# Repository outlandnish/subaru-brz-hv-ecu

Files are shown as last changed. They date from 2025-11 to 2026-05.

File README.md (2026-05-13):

# Subaru BRZ HV ECU

> **SAFETY NOTICE:** This system controls high-voltage contactors on a traction battery pack.
> Incorrect firmware can result in arc flash, fire, or electrocution. Do not flash untested builds
> to hardware connected to a live HV pack.

This is the HV ECU for a Subaru BRZ EV conversion. It manages:
- **Battery management** — cell voltage monitoring, balancing, and protection via NXP MC33772 BCC ICs
- **HV contactor control** — precharge, engage, and safe shutdown via DRV8874 H-bridge drivers
- **CAN communication** — IVT-S current/voltage shunt (HV CAN), CHAdeMO EVSE controller (M3 CAN)
- **CANopen** — parameter access and spot-value reporting via libopeninv

## Hardware

See [`hardware/`](hardware/) for schematics and pin maps.

Key specs:
- MCU: STM32F413VH running FreeRTOS
- 16 Taycan modules (8 per BCC chain, two MC33772 chains)
- DRV8874 H-bridge drivers for HV and AC contactors
- IVT-S 1000 A current shunt on HV CAN bus
- CHAdeMO controller (Foccci) on M3 CAN bus

## Getting Started

Clone with submodules:

```bash
git clone --recurse-submodules <repo-url>
# or after a plain clone:
git submodule update --init --recursive
```

## Building and Flashing

This project uses [PlatformIO](https://platformio.org/).

```bash
# Build main firmware
pio run -e hv-ecu

# Flash via ST-Link
pio run -e hv-ecu --target upload

# Serial monitor (115200 baud)
pio device monitor
```

## First-Boot Procedure

1. Flash firmware with ST-Link connected and HV pack **disconnected**.
2. Open a serial monitor at 115200 baud.
3. Type `status` to verify BCC devices are detected and cell voltages are sensible.
4. Type `params` to review default charge parameters before connecting HV.
5. Connect HV pack. Type `hv connect` to initiate precharge sequence.

## Running Tests

Unit tests run on-target via PlatformIO Unity:

```bash
pio test -e bms-test
```

## License

MIT — see [LICENSE](LICENSE).

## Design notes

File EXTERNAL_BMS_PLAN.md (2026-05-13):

# BMS CAN Protocol v0.1
**Status:** Draft  
**Target Hardware:** Dual-chain MC33772B BMS with Taycan 6S2P modules  
**CAN Bus Speed:** 500 kbps  
**CRC Algorithm:** CRC-8/AUTOSAR (polynomial 0x2F, init 0xFF, reflect in/out none, final XOR 0xFF)

---

## Table of Contents

1. [Overview](#1-overview)
2. [Physical Layer](#2-physical-layer)
3. [Frame Map](#3-frame-map)
4. [Ecosystem Broadcast Frames (0x351–0x35C)](#4-ecosystem-broadcast-frames)
5. [Cell Voltage Frames (0x400–0x401)](#5-cell-voltage-frames-0x400-0x401)
6. [Balancing Status Frame (0x402)](#6-balancing-status-frame-0x402)
7. [Temperature Frame (0x403)](#7-temperature-frame-0x403)
8. [BMS Config Frame (0x404)](#8-bms-config-frame-0x404)
9. [Contactor Status Frame (0x405)](#9-contactor-status-frame-0x405)
10. [UDS Diagnostic Interface](#10-uds-diagnostic-interface)
    - [Sessions and Security](#101-sessions-and-security)
    - [Data Identifiers](#102-data-identifiers)
    - [Fault Codes (DTCs)](#103-fault-codes-dtcs)
    - [Routine Control](#104-routine-control)
    - [Firmware Update](#105-firmware-update)
11. [Timing](#11-timing)
12. [CRC Calculation](#12-crc-calculation)

---

## 1. Overview

This document defines the CAN communication protocol for a dual-chain BMS supporting Porsche Taycan battery modules. Each module contains one MC33772B IC managing 6 cells in a 6S2P configuration. The protocol operates at 500 kbps and is structured in three layers:

| Layer | Frames | Purpose |
|---|---|---|
| Ecosystem Broadcast | 0x351–0x35C | Pack-level data. Compatible with SimpBMS, Victron, SMA, Fronius, and most aftermarket EV conversion chargers and inverters |
| Custom Broadcast | 0x400–0x405 | Per-module cell voltages, balancing status, temperatures, BMS config, contactor state |
| UDS Diagnostic | 0x7E0 / 0x7E8 | Configuration, fault codes, balancing parameters, contactor config, firmware update |

### Hardware Assumptions

- **Chains:** 2 (Chain 0 and Chain 1)
- **Max modules per chain:** 15 (30 total)
- **Cells per module:** 6 (always — Taycan 6S2P)
- **Max total cells:** 180
- **Temperature sensors per module:** 2x external NTC (Temp_A, Temp_B) + 1x MC33772B internal die (Temp_Die)
- **Contactors:** Up to 4 (K1–K4)
- **Current/voltage sensing:** IVT-S

---

## 2. Physical Layer

| Parameter | Value |
|---|---|
| Bus speed | 500 kbps |
| Frame format | CAN 2.0B, 11-bit standard IDs |
| Termination | 120 Ω at each end of bus |
| BMS UDS request ID | 0x7E0 |
| BMS UDS response ID | 0x7E8 |
| CRC algorithm | CRC-8/AUTOSAR |

---

## 3. Frame Map

| CAN ID | Name | Type | Rate | Description |
|---|---|---|---|---|
| 0x351 | ChargeVoltageLimit | Broadcast | 1000 ms | Max charge voltage and current limits |
| 0x355 | StateOfCharge | Broadcast | 1000 ms | SOC and SOH |
| 0x356 | PackSummary | Broadcast | 500 ms | Pack voltage, current, temperature |
| 0x359 | FaultFlags | Broadcast | 500 ms | Aggregate protection fault flags |
| 0x35C | ChargerControl | Broadcast | 1000 ms | Charger enable/disable flags |
| 0x400 | CellVoltages_1_3 | Broadcast (MUX) | 100 ms/module | Cells 1–3 per module. MUX = module index (0–29) |
| 0x401 | CellVoltages_4_6 | Broadcast (MUX) | 100 ms/module | Cells 4–6 per module. MUX = module index (0–29) |
| 0x402 | BalancingStatus | Broadcast (MUX) | 500 ms/module | Per-module balancing bitmask, mode, and target. MUX = module index (0–29) |
| 0x403 | Temperature | Broadcast (MUX) | 500 ms/module | Per-module Temp_A, Temp_B, Temp_Die. MUX = module index (0–29) |
| 0x404 | BMSConfig | Broadcast | On change + 5 s | Chain topology, module counts, BMS state, protocol version |
| 0x405 | ContactorStatus | Broadcast | 100 ms | State of K1–K4 and pre-charge status |
| 0x406 | ExtPackSummary | Broadcast | 500 ms | High-resolution pack voltage (1 mV/LSB) and current (1 mA/LSB) for high-voltage packs |
| 0x7E0 | UDS Request | Request/Response | On demand | ISO 14229 diagnostic requests from external tool |
| 0x7E8 | UDS Response | Request/Response | On demand | ISO 14229 diagnostic responses from BMS |

---

## 4. Ecosystem Broadcast Frames

These frames follow the SimpBMS/BYD/Pylontech broadcast format. Compatible with:

- **Chargers:** Victron MultiPlus/Quattro, SMA Sunny Island, Fronius Symo/Gen24, KEBA P30
- **Inverters:** Victron VE.Can ecosystem, OpenInverter-based systems
- **Monitors:** SimpBMS, Batrium WatchMon (BYD/Pylontech mode)

The minimum required frames for charger compatibility are **0x351, 0x355, and 0x35C**.

### 0x351 — Charge Voltage & Current Limits

Transmitted every 1000 ms.

| Byte | Signal | Bits | Encoding | Description |
|---|---|---|---|---|
| 0–1 | ChargeVoltage | 16 | 10 mV/LSB, uint16 | Maximum charge voltage. Ecosystem standard (Victron/SMA/Fronius). Max encodable: 655.35 V — clamp to UINT16_MAX for packs above 655 V |
| 2–3 | ChargeCurrentLimit | 16 | 100 mA/LSB, uint16 | Maximum charge current |
| 4–5 | DischargeCurrentLimit | 16 | 100 mA/LSB, uint16 | Maximum discharge current |
| 6–7 | DischargeVoltage | 16 | 10 mV/LSB, uint16 | Minimum discharge voltage. Ecosystem standard. Same 655 V ceiling applies |

### 0x355 — State of Charge / Health

Transmitted every 1000 ms.

| Byte | Signal | Bits | Encoding | Description |
|---|---|---|---|---|
| 0–1 | SOC | 16 | 0.01%/LSB, uint16 | State of charge (0–10000 = 0.00–100.00%) |
| 2–3 | SOH | 16 | 0.01%/LSB, uint16 | State of health (0–10000 = 0.00–100.00%) |
| 4–5 | SOC_High | 16 | 0.01%/LSB, uint16 | High precision SOC (same scale, same value) |
| 6–7 | reserved | 16 | — | Set to 0x0000 |

> **Note:** SOH is user-configurable via UDS DID 0xD105. DCIR-based automatic SOH estimation is reserved for a future revision.

### 0x356 — Pack Summary

Transmitted every 500 ms.

| Byte | Signal | Bits | Encoding | Description |
|---|---|---|---|---|
| 0–1 | PackVoltage | 16 | 10 mV/LSB, int16 | Total pack voltage. Ecosystem standard. Overflows above 327 V — use 0x406 for high-voltage packs |
| 2–3 | PackCurrent | 16 | 100 mA/LSB, int16 | Pack current. Positive = charging, negative = discharging |
| 4–5 | PackTemp | 16 | 0.1°C/LSB, int16 | Highest temperature across all NTC sensors. 0x7FFF = invalid/not yet available |
| 6–7 | reserved | 16 | — | Set to 0x0000 |

### 0x359 — Fault Flags

Transmitted every 500 ms.

| Byte | Signal | Bits | Encoding | Description |
|---|---|---|---|---|
| 0 | ProtectionFlags_0 | 8 | Bitmask | Bit 0: OVP, Bit 1: UVP, Bit 2: OTP, Bit 3: UTP |
| 1 | ProtectionFlags_1 | 8 | Bitmask | Bit 0: OCP charge, Bit 1: OCP discharge |
| 2 | WarnFlags_0 | 8 | Bitmask | Bit 0: High V warn, Bit 1: Low V warn, Bit 2: High T warn |
| 3 | WarnFlags_1 | 8 | Bitmask | Bit 0: High charge current warn, Bit 1: High discharge current warn |
| 4 | ActiveModules | 8 | Count | Number of active modules |
| 5 | BalancingModules | 8 | Count | Number of modules currently balancing |
| 6–7 | reserved | 16 | — | Set to 0x0000 |

### 0x35C — Charger Control

Transmitted every 1000 ms.

| Byte | Signal | Bits | Encoding | Description |
|---|---|---|---|---|
| 0 | ChargerFlags | 8 | Bitmask | Bit 0: Charge enable, Bit 1: Force charge, Bit 2: Discharge enable |
| 1–7 | reserved | 56 | — | Set to 0x00 |

---

## 5. Cell Voltage Frames (0x400–0x401)

Cell voltages for each module are split across two independent CAN IDs, each carrying 3 of the 6 cells. Both frames use a standard MUX byte equal to the global module index (0–29) and are transmitted independently at 100 ms per module.

**Global module index convention:**
- Chain 0 modules: index 0–14
- Chain 1 modules: index 15–29

### 0x400 — Cell Voltages, Cells 1–3

Transmitted every 100 ms per module.

| Byte | Signal | Bits | Encoding | Description |
|---|---|---|---|---|
| 0 | MUX | 8 | Module index (0–29) | Global module index |
| 1–2 | Cell1_Voltage | 16 | 1 mV/LSB, uint16 | Cell 1 voltage |
| 3–4 | Cell2_Voltage | 16 | 1 mV/LSB, uint16 | Cell 2 voltage |
| 5–6 | Cell3_Voltage | 16 | 1 mV/LSB, uint16 | Cell 3 voltage |
| 7 | CRC8 | 8 | CRC-8/AUTOSAR | CRC over bytes 0–6 |

### 0x401 — Cell Voltages, Cells 4–6

Transmitted every 100 ms per module.

| Byte | Signal | Bits | Encoding | Description |
|---|---|---|---|---|
| 0 | MUX | 8 | Module index (0–29) | Global module index |
| 1–2 | Cell4_Voltage | 16 | 1 mV/LSB, uint16 | Cell 4 voltage |
| 3–4 | Cell5_Voltage | 16 | 1 mV/LSB, uint16 | Cell 5 voltage |
| 5–6 | Cell6_Voltage | 16 | 1 mV/LSB, uint16 | Cell 6 voltage |
| 7 | CRC8 | 8 | CRC-8/AUTOSAR | CRC over bytes 0–6 |

> **Note:** 0x400 and 0x401 are transmitted independently at the same rate. A receiver can expect both frames for each module index within the same 100 ms cycle. Frames for inactive modules (index >= Total_Modules from 0x404) are not transmitted.

---

## 6. Balancing Status Frame (0x402)

Broadcasts per-module balancing state. One frame per module per cycle, MUX = global module index.

### Frame Layout

Transmitted every 500 ms per module.

| Byte | Signal | Bits | Encoding | Description |
|---|---|---|---|---|
| 0 | MUX | 8 | Module index (0–29) | Global module index |
| 1 | Balance_Mask | 8 | Bitmask | Bits 0–5: cell N+1 currently balancing. Bits 6–7 reserved, set to 0 |
| 2 | Balance_Mode | 8 | Enum | 0x00 = Disabled, 0x01 = Delta-V, 0x02 = Absolute target |
| 3–4 | Balance_Param | 16 | 1 mV/LSB, uint16 | Mode 0x01: delta-V threshold in mV. Mode 0x02: absolute target voltage in mV |
| 5–6 | reserved | 16 | — | Set to 0x0000 |
| 7 | CRC8 | 8 | CRC-8/AUTOSAR | CRC over bytes 0–6 |

### Balance_Mode Encoding

| Value | Mode | Balance_Param Meaning |
|---|---|---|
| 0x00 | Disabled | Ignored — set to 0x0000 |
| 0x01 | Delta-V | Threshold in mV above minimum cell voltage. Balance any cell where V_cell > V_min + threshold |
| 0x02 | Absolute | Target voltage in mV. Balance any cell where V_cell > target |

> **Note:** Balance_Mode and Balance_Param are global settings repeated in every module frame so any single frame is self-contained. Balancing is controlled autonomously by the BMS. Use UDS Routine Control service 0xD001 to trigger a manual balance cycle.

---

## 7. Temperature Frame (0x403)

Broadcasts per-module temperature readings. One frame per module per cycle, MUX = global module index.

### Frame Layout

Transmitted every 500 ms per module.

| Byte | Signal | Bits | Encoding | Description |
|---|---|---|---|---|
| 0 | MUX | 8 | Module index (0–29) | Global module index |
| 1–2 | Temp_A | 16 | 0.01°C/LSB, int16 | NTC thermistor A. Range: −327.68°C to +327.67°C |
| 3–4 | Temp_B | 16 | 0.01°C/LSB, int16 | NTC thermistor B. Range: −327.68°C to +327.67°C |
| 5–6 | Temp_Die | 16 | 0.01°C/LSB, int16 | MC33772B internal die temperature |
| 7 | CRC8 | 8 | CRC-8/AUTOSAR | CRC over bytes 0–6 |

> **Note:** A value of 0x7FFF (32767) indicates an invalid or disconnected sensor. Die temperature has approximately 1°C internal resolution; sub-degree digits will be zero unless interpolation is applied.

---

## 8. BMS Config Frame (0x404)

Broadcasts BMS topology and state as a single fixed frame with no MUX. Transmitted on power-on, on any configuration change, and periodically every 5 seconds. Receivers should wait for this frame before parsing 0x400–0x403 to determine the active module count.

Configuration is **read-only via broadcast**. Write configuration via UDS only.

### Frame Layout

| Byte | Signal | Bits | Encoding | Description |
|---|---|---|---|---|
| 0 | Chain0_Modules | 8 | 0–15 | Number of active modules on chain 0 |
| 1 | Chain1_Modules | 8 | 0–15 | Number of active modules on chain 1 |
| 2 | Total_Modules | 8 | 0–30 | Total active modules across both chains |
| 3 | Protocol_Version | 8 | 0x01 | Protocol version. This document = 0x01 |
| 4 | BMS_State | 8 | Enum | See BMS_State encoding below |
| 5–6 | reserved | 16 | — | Set to 0x0000 |
| 7 | CRC8 | 8 | CRC-8/AUTOSAR | CRC over bytes 0–6 |

### BMS_State Encoding

| Value | State | Description |
|---|---|---|
| 0x00 | Init | BMS initialising, chain communication not yet established |
| 0x01 | Ready | BMS operational, HV system open |
| 0x02 | Active | HV system closed, normal operation |
| 0x03 | Balancing | Balancing in progress |
| 0x04 | Charging | Charge contactor closed, charging in progress |
| 0x05 | Fault | One or more active faults. See 0x359 and UDS DTCs for details |
| 0x06 | Precharge | Pre-charge sequence in progress |

---

## 9. Contactor Status Frame (0x405)

Broadcasts the state of all four contactors and the pre-charge sequence. Transmitted every 100 ms.

### Frame Layout

| Byte | Signal | Bits | Encoding | Description |
|---|---|---|---|---|
| 0 | Contactor_State | 8 | Bitmask | Bit 0: K1, Bit 1: K2, Bit 2: K3, Bit 3: K4. 1 = closed, 0 = open |
| 1 | Precharge_State | 8 | Enum | See Precharge_State encoding below |
| 2–3 | Precharge_Voltage | 16 | **100 mV/LSB, uint16** | IVT-S inverter-side voltage during pre-charge. Changed from 1 mV/LSB to avoid overflow above 65 V |
| 4–5 | Pack_Voltage | 16 | **100 mV/LSB, uint16** | IVT-S pack-side voltage. Changed from 1 mV/LSB to avoid overflow above 65 V |
| 6 | reserved | 8 | — | Set to 0x00 |
| 7 | CRC8 | 8 | CRC-8/AUTOSAR | CRC over bytes 0–6 |

### Precharge_State Encoding

| Value | State | Description |
|---|---|---|
| 0x00 | Idle | Pre-charge not active |
| 0x01 | In Progress | Pre-charge contactor closed, voltage rising |
| 0x02 | Complete | Delta-V threshold met, ready to close main positive |
| 0x03 | Timeout | Pre-charge did not complete within configured timeout |
| 0x04 | Fault | Pre-charge fault (welded contactor, voltage sensor fault, etc.) |

### Default Contactor Assignment

| Contactor | Default Role | Configurable via UDS |
|---|---|---|
| K1 | Main negative | Yes |
| K2 | Main positive | Yes |
| K3 | Pre-charge | Yes |
| K4 | Charge path | Yes |

> **Note:** Contactor roles and pre-charge completion threshold are configurable via UDS DIDs 0xD200–0xD206. Pre-charge completion is determined by IVT-S voltage delta (V_pack − V_inverter < threshold), not by a fixed timer.

---

## 10. Extended Pack Summary Frame (0x406)

High-resolution pack voltage and current for receivers that need sub-100 mV precision or support packs above 327 V. Not part of the ecosystem broadcast format — not parsed by Victron/SMA/Fronius chargers. Transmitted at the same rate as 0x356.

### Frame Layout

Transmitted every 500 ms.

| Byte | Signal | Bits | Encoding | Description |
|---|---|---|---|---|
| 0–3 | PackVoltage | 32 | 1 mV/LSB, uint32 | Total pack voltage, little-endian. Range 0–4294967 V |
| 4–7 | PackCurrent | 32 | 1 mA/LSB, int32 | Pack current, little-endian. Positive = charging, negative = discharging |

> **Note:** No CRC — frame is 8 bytes, all payload. Temperature is omitted until BCC NTC readback is wired in; use 0x403 for per-module temperatures in the meantime.

---

## 11. UDS Diagnostic Interface

The UDS interface provides configuration, fault management, and firmware update over ISO 14229. Accessible with any UDS-capable tool (Vector CANalyzer, PEAK PCAN, python-udsoncan, etc.).

| Parameter | Value |
|---|---|
| Request ID | 0x7E0 |
| Response ID | 0x7E8 |
| Transport layer | ISO 15765-2 CAN TP |
| Addressing | Physical (1:1) |

---

### 10.1 Sessions and Security

#### Diagnostic Sessions (Service 0x10)

| Session | ID | Capabilities | Timeout |
|---|---|---|---|
| Default | 0x01 | Read all DIDs, read DTCs | No timeout |
| Extended Diagnostic | 0x03 | Read + write all DIDs, clear DTCs, routine control | 5 s inactivity |
| Programming | 0x02 | Firmware update only | Must unlock Security Level 2 first |

#### Security Access (Service 0x27)

| Level | RequestSeed | SendKey | Required For |
|---|---|---|---|
| Level 1 | 0x01 | 0x02 | Write DIDs in extended session |
| Level 2 | 0x11 | 0x12 | Programming session (firmware update) |

> **Note:** Seed/key algorithm TBD. Minimum recommendation: HMAC-SHA256 with a device-unique seed. Three consecutive failed attempts must lock security access for 10 minutes.

---

### 10.2 Data Identifiers

#### Read-Only DIDs (Service 0x22 — Default Session)

| DID | Name | Size | Encoding | Description |
|---|---|---|---|---|
| 0xF190 | DeviceSerial | 17 B | ASCII | Device serial number |
| 0xF187 | PartNumber | 10 B | ASCII | BMS hardware part number |
| 0xF189 | SoftwareVersion | 4 B | uint8 × 4 | Major.Minor.Patch.Build |
| 0xF195 | HardwareVersion | 2 B | uint8 × 2 | Major.Minor |
| 0xD000 | BMS_State | 1 B | Enum | See BMS_State encoding in §8 |
| 0xD001 | Pack_Voltage | 4 B | int32, 1 mV/LSB | Total pack voltage from IVT-S |
| 0xD002 | Pack_Current | 4 B | int32, 1 mA/LSB | Pack current. Positive = charging |
| 0xD003 | Cell_Voltage_Min | 2 B | uint16, 1 mV/LSB | Minimum cell voltage across all cells |
| 0xD004 | Cell_Voltage_Max | 2 B | uint16, 1 mV/LSB | Maximum cell voltage across all cells |
| 0xD005 | Cell_Voltage_Delta | 2 B | uint16, 1 mV/LSB | Max − Min cell voltage |
| 0xD006 | Cell_Voltage_Avg | 2 B | uint16, 1 mV/LSB | Average cell voltage across all cells |
| 0xD007 | Temp_Max | 2 B | int16, 0.01°C/LSB | Highest NTC temperature across all modules |
| 0xD008 | Temp_Min | 2 B | int16, 0.01°C/LSB | Lowest NTC temperature across all modules |
| 0xD009 | SOC | 2 B | uint16, 0.01%/LSB | State of charge |
| 0xD00A | SOH | 2 B | uint16, 0.01%/LSB | State of health (user-configured) |
| 0xD00B | Cell_Voltages_All | 2 B × N×6 | uint16, 1 mV/LSB | All cell voltages sequentially. N = Total_Modules, 6 cells per module |
| 0xD00C | Temps_All | 2 B × N×3 | int16, 0.01°C/LSB | All temperatures sequentially: Temp_A, Temp_B, Temp_Die per module |
| 0xD00D | Balance_Status_All | 1 B × N | Bitmask | Per-module balance mask. N = Total_Modules |
| 0xD00E | Chain0_Modules | 1 B | uint8 | Active module count on chain 0 |
| 0xD00F | Chain1_Modules | 1 B | uint8 | Active module count on chain 1 |
| 0xD010 | Total_Modules | 1 B | uint8 | Total modules across both chains |
| 0xD011 | Contactor_State | 1 B | Bitmask | Current state of K1–K4. See §9 |
| 0xD012 | Precharge_State | 1 B | Enum | Current pre-charge state. See §9 |
| 0xD013 | IVT_Pack_Voltage | 4 B | int32, 1 mV/LSB | IVT-S pack-side voltage |
| 0xD014 | IVT_Inverter_Voltage | 4 B | int32, 1 mV/LSB | IVT-S inverter-side voltage |

#### Read/Write DIDs (Service 0x2E — Extended Session + Security Level 1)

**Balancing Configuration**

| DID | Name | Size | Encoding | Description |
|---|---|---|---|---|
| 0xD100 | Balance_Mode | 1 B | Enum | 0x00 = Disabled, 0x01 = Delta-V, 0x02 = Absolute |
| 0xD101 | Balance_DeltaV_Threshold | 2 B | uint16, 1 mV/LSB | Delta-V threshold in mV. Active when Balance_Mode = 0x01 |
| 0xD102 | Balance_Absolute_Target | 2 B | uint16, 1 mV/LSB | Absolute target voltage in mV. Active when Balance_Mode = 0x02 |
| 0xD103 | Balance_Inhibit_Pack_Voltage | 2 B | uint16, 10 mV/LSB | Minimum pack voltage below which balancing is inhibited |
| 0xD104 | Balance_Min_Cell_Voltage | 2 B | uint16, 1 mV/LSB | Minimum cell voltage below which that cell will not be balanced |

**SOC / SOH Configuration**

| DID | Name | Size | Encoding | Description |
|---|---|---|---|---|
| 0xD105 | SOH_Override | 2 B | uint16, 0.01%/LSB | User-configured SOH value written to 0x355 directly |
| 0xD106 | SOC_Method | 1 B | Enum | 0x00 = Coulomb counting, 0x01 = OCV lookup (reserved for future) |

**Protection Thresholds**

| DID | Name | Size | Encoding | Description |
|---|---|---|---|---|
| 0xD110 | OVP_Threshold | 2 B | uint16, 1 mV/LSB | Cell overvoltage protection trip threshold |
| 0xD111 | OVP_Warning | 2 B | uint16, 1 mV/LSB | Cell overvoltage warning threshold |
| 0xD112 | UVP_Threshold | 2 B | uint16, 1 mV/LSB | Cell undervoltage protection trip threshold |
| 0xD113 | UVP_Warning | 2 B | uint16, 1 mV/LSB | Cell undervoltage warning threshold |
| 0xD114 | OTP_Threshold | 2 B | int16, 0.01°C/LSB | Overtemperature protection trip threshold |
| 0xD115 | OTP_Warning | 2 B | int16, 0.01°C/LSB | Overtemperature warning threshold |
| 0xD116 | UTP_Threshold | 2 B | int16, 0.01°C/LSB | Undertemperature protection trip threshold |
| 0xD117 | UTP_Warning | 2 B | int16, 0.01°C/LSB | Undertemperature warning threshold |
| 0xD118 | OCP_Charge_Threshold | 4 B | uint32, 1 mA/LSB | Overcurrent protection threshold for charge |
| 0xD119 | OCP_Discharge_Threshold | 4 B | uint32, 1 mA/LSB | Overcurrent protection threshold for discharge |

**Contactor Configuration**

| DID | Name | Size | Encoding | Description |
|---|---|---|---|---|
| 0xD200 | K1_Role | 1 B | Enum | 0x00 = Main negative, 0x01 = Main positive, 0x02 = Pre-charge, 0x03 = Charge path, 0xFF = Disabled |
| 0xD201 | K2_Role | 1 B | Enum | Same encoding as K1_Role |
| 0xD202 | K3_Role | 1 B | Enum | Same encoding as K1_Role |
| 0xD203 | K4_Role | 1 B | Enum | Same encoding as K1_Role |
| 0xD204 | Precharge_Completion_Threshold | 2 B | uint16, 1 mV/LSB | Delta-V between pack and inverter side below which pre-charge is considered complete |
| 0xD205 | Precharge_Timeout | 2 B | uint16, 1 ms/LSB | Maximum pre-charge duration before fault |
| 0xD206 | Precharge_Min_Voltage | 2 B | uint16, 1 mV/LSB | Minimum inverter-side voltage to consider pre-charge complete |

**Chain Configuration**

| DID | Name | Size | Encoding | Description |
|---|---|---|---|---|
| 0xD300 | Chain0_Module_Count | 1 B | uint8, 0–15 | Number of modules on chain 0 |
| 0xD301 | Chain1_Module_Count | 1 B | uint8, 0–15 | Number of modules on chain 1 |

> **Note:** Writing chain module counts triggers a BMS re-initialisation sequence. The BMS transitions to Init state, re-enumerates the chain, then returns to Ready state. A 0x404 config broadcast is sent immediately after re-initialisation completes.

---

### 10.3 Fault Codes (DTCs)

Fault codes are read using UDS Service 0x19 (ReadDTCInformation) and cleared using Service 0x14 (ClearDiagnosticInformation). Clearing DTCs requires Extended Session + Security Level 1.

| DTC | Name | Description |
|---|---|---|
| 0xC00001 | Cell_Overvoltage | One or more cells exceeded OVP_Threshold |
| 0xC00002 | Cell_Undervoltage | One or more cells fell below UVP_Threshold |
| 0xC00003 | Overtemperature | One or more sensors exceeded OTP_Threshold |
| 0xC00004 | Undertemperature | One or more sensors fell below UTP_Threshold |
| 0xC00005 | OCP_Charge | Charge current exceeded OCP_Charge_Threshold |
| 0xC00006 | OCP_Discharge | Discharge current exceeded OCP_Discharge_Threshold |
| 0xC00007 | Precharge_Timeout | Pre-charge did not complete within Precharge_Timeout |
| 0xC00008 | Precharge_Fault | Pre-charge fault (welded contactor suspected or voltage sensor fault) |
| 0xC00009 | Contactor_Fault | Contactor feedback mismatch (commanded state ≠ measured state) |
| 0xC0000A | Chain0_Comm_Fault | SPI communication fault on chain 0 |
| 0xC0000B | Chain1_Comm_Fault | SPI communication fault on chain 1 |
| 0xC0000C | IVT_Comm_Fault | IVT-S communication fault |
| 0xC0000D | Cell_Voltage_Sensor_Fault | MC33772B reported internal voltage measurement fault |
| 0xC0000E | Temp_Sensor_Fault | One or more temperature sensors reading 0x7FFF (disconnected or out of range) |
| 0xC0000F | Config_Invalid | Stored configuration checksum failure — BMS running with defaults |

---

### 10.4 Routine Control

Routines are invoked using UDS Service 0x31 (RoutineControl). All routines require Extended Session + Security Level 1.

| Routine ID | Name | Description |
|---|---|---|
| 0xD001 | Manual_Balance_Cycle | Triggers a single balancing pass using current Balance_Mode and Balance_Param. Returns when complete or on fault |
| 0xD002 | Balance_Stop | Immediately halts any active balancing on all modules |
| 0xD003 | Contactor_Open_All | Opens all contactors. For service/safety use only |
| 0xD004 | Precharge_Sequence | Manually triggers the pre-charge and close sequence |
| 0xD005 | Chain_Reinit | Re-initialises SPI chain enumeration without full BMS restart |
| 0xD006 | Clear_All_DTCs | Clears all stored DTCs. Equivalent to Service 0x14 with group 0xFFFFFF |
| 0xD007 | Save_Config | Persists all current DID values to non-volatile storage |

---

### 10.5 Firmware Update

Firmware update uses the standard UDS programming sequence. Programming session requires Security Level 2.

**Sequence:**

```
1. 0x10 0x02                         — Enter programming session
2. 0x27 0x11 → 0x27 0x12 <key>      — Unlock Security Level 2
3. 0x34 ...                          — Request download (address, length, compression)
4. 0x36 ... (repeat)                 — Transfer data blocks
5. 0x37                              — Request transfer exit
6. 0x31 0xFF 0x01                    — Validate firmware checksum (routine 0xFF01)
7. 0x11 0x01                         — ECU reset
```

> **Note:** The BMS will not close contactors while in programming session. If contactors are already closed when a programming session is requested, the request will be rejected with NRC 0x22 (conditionsNotCorrect).

---

## 11. Timing

| Frame | Interval | Notes |
|---|---|---|
| 0x351 | 1000 ms | |
| 0x355 | 1000 ms | |
| 0x356 | 500 ms | |
| 0x359 | 500 ms | |
| 0x35C | 1000 ms | |
| 0x400 | 100 ms/module | Full cycle = Total_Modules × 100 ms |
| 0x401 | 100 ms/module | Full cycle = Total_Modules × 100 ms. Transmitted independently of 0x400 |
| 0x402 | 500 ms/module | Full cycle = Total_Modules × 500 ms |
| 0x403 | 500 ms/module | Full cycle = Total_Modules × 500 ms |
| 0x404 | 5000 ms + on change | Always transmitted on power-on before other custom frames |
| 0x405 | 100 ms | |

> **Note:** At maximum configuration (30 modules), 0x400 and 0x401 each complete a full cycle in 3000 ms (30 frames × 100 ms). Bus load at maximum configuration at 500 kbps is well under 10%.

---

## 12. CRC Calculation

All custom broadcast frames (0x400–0x405) include a CRC-8/AUTOSAR checksum in byte 7, calculated over bytes 0–6.

**Algorithm parameters:**

| Parameter | Value |
|---|---|
| Polynomial | 0x2F |
| Initial value | 0xFF |
| Input reflection | No |
| Output reflection | No |
| Final XOR | 0xFF |
| Check value | 0xDF (CRC of ASCII "123456789") |

**Reference C implementation:**

```c
static const uint8_t crc8_autosar_table[256] = {
    0x00, 0x2F, 0x5E, 0x71, 0xBC, 0x93, 0xE2, 0xCD,
    /* ... full 256-entry table ... */
};

uint8_t crc8_autosar(const uint8_t *data, size_t len) {
    uint8_t crc = 0xFF;
    for (size_t i = 0; i < len; i++) {
        crc = crc8_autosar_table[crc ^ data[i]];
    }
    return crc ^ 0xFF;
}

/* Usage: byte 7 = crc8_autosar(frame, 7) */
```

> **Note:** The MC33772B uses CRC-8/AUTOSAR internally on its SPI bus. The same lookup table used for SPI communication can be reused directly for CAN frame CRCs.

---

*BMS CAN Protocol v0.1 — Draft. All frame definitions, DID addresses, and DTC codes are subject to change prior to v1.0 release.*

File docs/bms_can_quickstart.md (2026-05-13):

# BMS CAN Broadcaster — Integrator Quickstart

**DBC file:** [`bms_can_protocol.dbc`](../bms_can_protocol.dbc)

---

## 1. Hardware Setup

| Signal | Pin | Notes |
|---|---|---|
| HV CAN RX | `HV_CAN_RX` | 500 kbps, 120 Ω termination required at each end |
| HV CAN TX | `HV_CAN_TX` | |
| IVT-S shunt | HV CAN bus | Responds to frames 0x521–0x528 and 0x511 |
| BCC chain 0 | SPI (`BCC0_TX_CS`, `BCC0_INTB`, `BCC0_ENABLE`) | MC33772B, up to 15 modules |
| BCC chain 1 | SPI (`BCC1_TX_CS`, `BCC1_INTB`, `BCC1_ENABLE`) | MC33772B, up to 15 modules |
| Debug serial | 115200 baud | Available in `DEBUG` builds |

All CAN broadcast frames (0x351–0x405) are transmitted on **HV CAN at 500 kbps**.

---

## 2. Startup Sequence

On power-on the BMS transmits **0x404 (BMSConfig)** immediately before any other custom frames. Receivers should wait for this frame to determine the active module count before parsing 0x400–0x403.

The 0x404 frame then repeats every **5 seconds**.

---

## 3. Frame Summary

| CAN ID | Name | Rate | Purpose |
|---|---|---|---|
| 0x351 | ChargeVoltageLimit | 1000 ms | Pack charge/discharge voltage and current limits — ecosystem format |
| 0x355 | StateOfCharge | 1000 ms | SOC and SOH |
| 0x356 | PackSummary | 500 ms | Pack voltage, current, temperature |
| 0x359 | FaultFlags | 500 ms | Protection and warning flags, active module count |
| 0x35C | ChargerControl | 1000 ms | Charge enable / discharge enable |
| 0x400 | CellVoltages_1_3 | 100 ms/module | Cells 1–3, MUX = module index |
| 0x401 | CellVoltages_4_6 | 100 ms/module | Cells 4–6, MUX = module index |
| 0x402 | BalancingStatus | 500 ms/module | Per-module balance mask, mode, target |
| 0x403 | Temperature | 500 ms/module | Temp_A, Temp_B, Temp_Die per module |
| 0x404 | BMSConfig | 5000 ms + on change | Chain topology, module count, BMS state |
| 0x405 | ContactorStatus | 100 ms | K1–K4 state, pre-charge state and voltages |
| 0x406 | ExtPackSummary | 500 ms | High-resolution pack voltage (1 mV/LSB) and current (1 mA/LSB) — non-ecosystem |

Frames 0x351, 0x355, and 0x35C are the **minimum required** for charger compatibility with Victron, SMA, and Fronius systems.

### Module indexing

Modules are addressed globally across both chains:

- **Chain 0:** module index 0–14
- **Chain 1:** module index 15–29

The active count for each chain is broadcast in 0x404 (`Chain0_Modules`, `Chain1_Modules`). Only indices below the active count produce frames.

---

## 4. Signal Encodings

Key encoding decisions that differ from common BMS implementations:

| Frame | Signal | Encoding | Why |
|---|---|---|---|
| 0x356 | PackVoltage | int16, **10 mV/LSB** | Ecosystem standard — overflows above 327 V, use 0x406 for high-voltage packs |
| 0x406 | PackVoltage | uint32, **1 mV/LSB** | Extended frame — 1 mV resolution, supports up to ~4294 V |
| 0x406 | PackCurrent | int32, **1 mA/LSB** | Extended frame — 1 mA resolution |
| 0x405 | Precharge_Voltage | uint16, **100 mV/LSB** | uint16 at 1 mV/LSB overflows at 65 V |
| 0x405 | Pack_Voltage | uint16, **100 mV/LSB** | Same reason |
| 0x351 | ChargeVoltage | uint16, **10 mV/LSB** | Ecosystem standard — Victron/SMA/Fronius require this encoding |
| 0x351 | DischargeVoltage | uint16, **10 mV/LSB** | Ecosystem standard. Max encodable: 655.35 V |
| 0x356 | PackTemp | int16, 0.1°C/LSB | **0x7FFF = invalid** — BCC NTC readback not yet wired in firmware |
| 0x403 | Temp_A/B/Die | int16, 0.01°C/LSB | **0x7FFF = invalid** — same reason |

---

## 5. CRC

Frames 0x400–0x405 include a **CRC-8/AUTOSAR** checksum in byte 7, calculated over bytes 0–6.

| Parameter | Value |
|---|---|
| Polynomial | 0x2F |
| Initial value | 0xFF |
| Input/output reflection | None |
| Final XOR | 0xFF |
| Check value | 0xDF (CRC of "123456789") |

Frames 0x351–0x35C do **not** include a CRC (ecosystem format).

---

## 6. Configuration

### 6.1 Compile-time parameters (set before flashing)

Parameters are stored in non-volatile memory and loaded at boot. They can be updated by writing to parameter storage before flashing. There is currently **no runtime configuration interface** — UDS (§10 of the protocol spec) is planned but not yet implemented.

#### BCC Hardware

| Parameter | Unit | Range | Default | Description |
|---|---|---|---|---|
| `bcc0DeviceCount` | — | 0–15 | 8 | Number of MC33772B devices on chain 0 |
| `bcc0DeviceType` | 0=MC33771, 1=MC33772 | 0–1 | 1 | IC type for chain 0 |
| `bcc1DeviceCount` | — | 0–15 | 8 | Number of MC33772B devices on chain 1 |
| `bcc1DeviceType` | 0=MC33771, 1=MC33772 | 0–1 | 1 | IC type for chain 1 |

#### Battery

| Parameter | Unit | Range | Default | Description |
|---|---|---|---|---|
| `targetCellVolt` | mV | 3000–4300 | 3600 | Per-cell charge target voltage |
| `batteryCapacity` | Ah | 10–200 | 50 | Total pack capacity (used for SOC coulomb counting) |
| `minSocPercent` | % | 0–50 | 10 | SOC floor — BMS will not discharge below this |
| `maxSocPercent` | % | 50–100 | 100 | SOC ceiling |
| `initSocPercent` | % | 0–100 | 50 | Initial SOC estimate on first boot before coulomb counting converges |

#### Charging

| Parameter | Unit | Range | Default | Description |
|---|---|---|---|---|
| `maxChargeCurrent` | A | 5–200 | 30 | Maximum charge current limit (broadcast in 0x351 `ChargeCurrentLimit`) |
| `balanceThreshold` | mV | 10–200 | 50 | Cell delta-V above which balancing activates (also broadcast in 0x402 `Balance_Param`) |
| `balanceTarget` | mV | 5–100 | 10 | Cell delta-V below which balancing deactivates and charging resumes |
| `balanceTimerMin` | min | 1–60 | 5 | Maximum duration of a single balancing pass |
| `measureInterval` | ms | 10–1000 | 20 | Voltage measurement interval |

#### HV System

| Parameter | Unit | Range | Default | Description |
|---|---|---|---|---|
| `prechargeMargin` | V | 1–50 | 10 | Acceptable V_pack − V_inverter delta for precharge completion |
| `prechargeTimeout` | ms | 1000–30000 | 5000 | Maximum precharge duration before fault |
| `prechargeCheckInt` | ms | 10–1000 | 100 | How often precharge voltage is checked |

#### Contactor PWM (economizer mode)

| Parameter | Unit | Range | Default | Description |
|---|---|---|---|---|
| `pwmFrequency` | Hz | 1000–50000 | 25000 | Contactor PWM frequency |
| `engageDuty` | % | 50–100 | 100 | Duty cycle during initial engagement |
| `holdDuty` | % | 10–80 | 30 | Hold duty cycle after engagement |
| `engageTime` | ms | 10–500 | 100 | Duration of full-duty engage phase before switching to hold |

#### Timing

| Parameter | Unit | Range | Default | Description |
|---|---|---|---|---|
| `commTimeout` | ms | 1000–30000 | 5000 | BCC communication loss timeout before fault |
| `faultCheckInt` | ms | 100–30000 | 5000 | How often fault registers are read from BCC |

### 6.2 UDS configuration (planned — not yet implemented)

The protocol spec defines a full UDS interface (0x7E0 / 0x7E8) for runtime configuration of balancing parameters, protection thresholds, contactor roles, SOH, and chain topology. This is not implemented in the current firmware. All configuration is currently done at flash time.

See `EXTERNAL_BMS_PLAN.md §11` for the planned DID map.

---

## 7. Read-only diagnostic values

These values are maintained internally by the BMS and readable via the parameter interface (not broadcast over CAN).

| Value | Unit | Description |
|---|---|---|
| `packVoltage` | V | IVT-S V1 pack-side voltage |
| `packCurrent` | A | IVT-S current |
| `soc` | % | State of charge (integer) |
| `socPrecise` | % | State of charge (float) |
| `cellVoltMin` | mV | Minimum cell voltage across all cells |
| `cellVoltMax` | mV | Maximum cell voltage across all cells |
| `cellVoltDiff` | mV | Max − Min cell voltage |
| `safeChargeCurrent` | A | Computed safe charge current |
| `bmsState` | — | Internal BMS state enum |
| `hvState` | — | HV state machine state |
| `bcc0Initialized` | — | BCC chain 0 init status |
| `bcc1Initialized` | — | BCC chain 1 init status |
| `faultStatus` | — | Raw BCC fault register bitmask |
| `lasterr` | — | Last fault code |
| `ivtCurrent` | A | IVT-S current (raw CAN value) |
| `ivtVoltage1` | V | IVT-S V1 (pack side) |
| `ivtVoltage2` | V | IVT-S V2 (inverter side) |
| `ivtTemperature` | C | IVT-S temperature |
| `ivtPower` | kW | IVT-S computed power |

---

## 8. Fault flags (0x359)

| Bit | Signal | Source |
|---|---|---|
| Byte 0, bit 0 | OVP | BCC `CELL_OV` fault register |
| Byte 0, bit 1 | UVP | BCC `CELL_UV` fault register |
| Byte 0, bit 2 | OTP | BCC `AN_OT_UT` register, over-temp bits |
| Byte 0, bit 3 | UTP | BCC `AN_OT_UT` register, under-temp bits |
| Byte 1, bit 0 | OCP_Charge | IVT current > 0 while `has_faults()` |
| Byte 1, bit 1 | OCP_Discharge | IVT current < 0 while `has_faults()` |
| Byte 2, bits 0–2 | WarnHighV, WarnLowV, WarnHighT | Same sources as protection flags |
| Byte 4 | ActiveModules | 0 if BCC comm fault, else total module count |
| Byte 5 | BalancingModules | Total modules when in `BMS_CellBalancing` state, else 0 |

---

## 9. BMS state machine

States broadcast in 0x404 `BMS_State` and 0x405 `Precharge_State`:

```
              ┌─────────┐
   boot       │  Init   │
─────────────►│  0x00   │
              └────┬────┘
                   │ BCC chains enumerated
              ┌────▼────┐
              │  Ready  │◄──── HV_Shutdown
              │  0x01   │
              └────┬────┘
                   │ start_charging() / start_drive_mode()
          ┌────────▼────────┐
          │   Precharge     │
          │     0x06        │
          └────────┬────────┘
                   │ V_inverter ≈ V_pack (within prechargeMargin)
          ┌────────▼────────┐
          │ Charging/Active │
          │   0x04 / 0x02   │
          └────────┬────────┘
                   │ cell delta-V > balanceThreshold
          ┌────────▼────────┐
          │   Balancing     │
          │     0x03        │
          └─────────────────┘
                   
  Any state ──fault──► Fault (0x05)
```

---

## 10. Charger integration (ecosystem frames)

For Victron/SMA/Fronius chargers, the minimum subscription is:

1. **0x351** — pack charge voltage and current limits (sent every 1 s)
2. **0x355** — SOC and SOH (sent every 1 s)
3. **0x35C** — charge enable flag (sent every 1 s)

The charger must see all three frames within its timeout window (typically 3–5 s) to remain enabled. The `ChargeEnable` bit in 0x35C goes high when `BMS_State` is `Charging` or `Idle` and no faults are active. `DischargeEnable` goes high when `HV_State` is `Active` and no faults are active.

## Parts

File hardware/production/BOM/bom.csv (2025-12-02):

Designator | Footprint | Quantity | Value | LCSC Part #
C1, C9 | 0402 | 2 | 1 nF
C10, C12, C2, C4 | 0402 | 4 | 100 nF
C11, C21, C3, C44 | 0805 | 4 | 2.2 uF
C13, C28, C29, C5 | 0402 | 4 | 4.7 nF
C14, C15, C6, C7 | 0402 | 4 | 68 pF
C16, C8 | 0402 | 2 | 100 pF
C17, C18 | 0402 | 2 | 6 pF
C19, C20 | 0402 | 2 | 18 pF
C22, C23, C24, C25, C30, C31, C32, C43 | 0402 | 8 | 0.1 uF
C26 | 0402 | 1 | 1.0 uF
C27 | 0805 | 1 | 4.7 uF
C34, C35, C36, C50, C52, C56, C58 | 0805 | 7 | 100nF | C49678
C37 | 0805 | 1 | 47pF | C14857
C38 | 0805 | 1 | 22pF | C1804
C39, C40, C42, C53, C54, C55, C59, C60, C61 | 1210 | 9 | 22uF | C12891
C41 | 0805 | 1 | 10 uF | C14857
C51, C57 | 0805 | 2 | 22nF | C1729
D1, D2, D3, D4 | SOD2512X110N | 4 | PESD5V0V1BA,115
D10, D11, D13, D14, D15, D16, D17, D5, D8, D9 | XL-1010RGBC-WS2812B | 10 | ~
D12 | 0603 | 1 | LED
D23, D24 | D_SMA | 2 | SS15
D6, D7 | SOT-23_ONS | 2 | SZNUP2105LT1G
IC1, IC2 | SOIC127P600X175-16N | 2 | MC33664ATL1EG
IC4, IC5 | SOP65P640X120-17N | 2 | DRV8874QPWPRQ1 | C1855818
J3 | ST-Link MINIV3 BTB | 1 | Conn_01x10_Pin
J4 | DTM1312PA12PBR008 | 1 | DTM1312PA12PBR008
L1 | L_6.3x6.3_H3 | 1 | 10uH | C408412
R1, R10, R11, R12, R13, R14, R2, R3, R4, R5, R6, R9 | 0402 | 12 | 10K
R15, R16, R7, R8 | 0603 | 4 | 75 R
R17 | 0603 | 1 | 10k
R18 | 0402 | 1 | 15k
R19 | 0402 | 1 | 3.3k
R24, R25, R26, R27 | 0603 | 4 | 60R .25W
R30, R36 | 0805 | 2 | 560 | C28636
R31, R37 | 0805 | 2 | 2k7 | C17530
R32 | 0603 | 1 | 680R
R33 | 0805 | 1 | 22k | C17560
R51 | 0805 | 1 | 100k | C149504
R52 | 0805 | 1 | 33k | C17633
T1, T2 | SOP254P940X572-6N | 2 | HM2103NLT
U1, U4 | SMA_UNI_STM | 2 | SMAJ16A-TR | C908770
U2, U3 | SOIC-8_3.9x4.9mm_P1.27mm | 2 | SN65HVD230
U5 | SOT-223-3_TabPin2 | 1 | AMS1117-3.3 | C6186
U7 | SOT-23-6 | 1 | TPS54302 | C311983
U9 | LQFP-100_14x14mm_P0.5mm | 1 | STM32F413VHTx
Y1 | Crystal_SMD_3215-2Pin_3.2x1.5mm | 1 | 32.768 kHz
Y2 | Crystal_SMD_HC49-SD | 1 | 8MHz

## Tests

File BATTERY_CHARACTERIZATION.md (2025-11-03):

# Battery Characterization Tool

This tool reads GUID, configuration registers, and fuse mirror data from up to 8 batteries on each BCC chain (BCC0 and BCC1) and outputs the data in CSV format.

## Overview

The battery characterization application is a separate PlatformIO environment that:
- Initializes both BCC0 and BCC1 chains
- Detects up to 8 MC33772C devices on each chain (16 batteries total)
- Reads GUID from each battery
- Reads all configuration registers (44 registers for MC33772C)
- Reads all fuse mirror data (32 fuse addresses for MC33772C)
- Outputs all data in CSV format via serial port

## Hardware Setup

1. Connect up to 8 batteries to BCC0 daisy chain
2. Connect up to 8 batteries to BCC1 daisy chain
3. Ensure proper power supply to the board
4. Connect ST-Link debugger or USB cable

## Building and Uploading

### Build the application
```bash
pio run -e battery-char
```

### Upload to board
```bash
pio run -e battery-char -t upload
```

## Capturing Data

### Method 1: Using Python Capture Script (Recommended)

The included Python script automatically captures serial output and saves it to a CSV file:

```bash
# Auto-detect port and use timestamped filename
python3 capture_battery_data.py

# Specify port and output file
python3 capture_battery_data.py --port /dev/ttyACM0 --output my_batteries.csv

# With custom timeout
python3 capture_battery_data.py --timeout 120
```

The script will:
- Auto-detect the serial port (or use specified port)
- Create a CSV file with timestamp
- Capture all data automatically
- Stop when characterization is complete

### Method 2: Manual Serial Monitor

```bash
# Using PlatformIO
pio device monitor

# Or using screen (Linux/Mac)
screen /dev/ttyACM0 115200

# Save output to file
pio device monitor > battery_data.txt
```

Then manually extract the CSV data from the output.

## CSV Output Format

The tool outputs data in the following CSV format:

```csv
BCC,CID,Field,Address,Value,Description
0,1,GUID,N/A,0x01ABCD1234,Device GUID
0,1,INIT,0x0001,0x1234,Initialization register
0,1,CELL_OV_UV,0x0010,0x5678,Configuration register
0,1,FUSE_00,0x00,0xABCD,Fuse mirror data
...
```

### CSV Columns:
- **BCC**: BCC controller number (0 or 1)
- **CID**: Cluster ID (1-8 for each device in the chain)
- **Field**: Register or data field name
- **Address**: Register address in hex
- **Value**: Register value in hex (or ERROR_N if read failed)
- **Description**: Description of the field

## Data Analysis

Once you have the CSV file, you can:

1. **Open in Excel/LibreOffice**: Import as CSV for easy viewing
2. **Filter by BCC**: See all data from one controller
3. **Filter by CID**: See all data from one battery
4. **Compare GUIDs**: Track individual batteries
5. **Analyze registers**: Compare configuration across batteries
6. **Check fuse data**: Verify factory calibration values

## Example Workflow

```bash
# 1. Build and upload the application
pio run -e battery-char -t upload

# 2. Wait a few seconds for the board to boot

# 3. Run the capture script
python3 capture_battery_data.py

# 4. The script will automatically save data to battery_data_YYYYMMDD_HHMMSS.csv

# 5. Open the CSV file in your favorite spreadsheet application
```

## Troubleshooting

### No devices detected
- Check battery connections
- Verify power supply
- Check enable pins are properly configured
- Verify daisy chain wiring

### Communication errors
- Reduce communication speed
- Check for electrical noise
- Verify SPI connections

### Serial port not found
- Check USB cable connection
- Verify ST-Link drivers installed
- Specify port manually: `python3 capture_battery_data.py --port /dev/ttyACM0`

### Incomplete data capture
- Increase timeout: `python3 capture_battery_data.py --timeout 120`
- Check for communication issues with batteries
- Review error messages in output

## Architecture Details

### Source Files
- `src/battery_char.cpp` - Main characterization application
- `src/hv-ecu-v0-pins.h` - Pin definitions
- `capture_battery_data.py` - Data capture helper script

### PlatformIO Environment
The `[env:battery-char]` environment in `platformio.ini`:
- Uses minimal dependencies (no FreeRTOS)
- Filters out main BMS application files
- Optimized for quick builds

### Data Collection Process
1. Initialize BCC0 and BCC1 controllers
2. Detect devices on each chain (scan CIDs 1-8)
3. For each detected device:
   - Read GUID
   - Read INIT register
   - Read all 44 configuration registers (MC33772C)
   - Read all 32 fuse mirror addresses
4. Output all data as CSV via serial

## Notes

- The tool assumes MC33772C (6-cell) devices by default
- Modify `devices_0[i] = BCC_DEVICE_MC33772` if using MC33771C (14-cell)
- Each device takes ~5-10 seconds to characterize
- Total time for 16 batteries: ~2-3 minutes
- Data is output in real-time as it's collected
- Press reset button to run characterization again

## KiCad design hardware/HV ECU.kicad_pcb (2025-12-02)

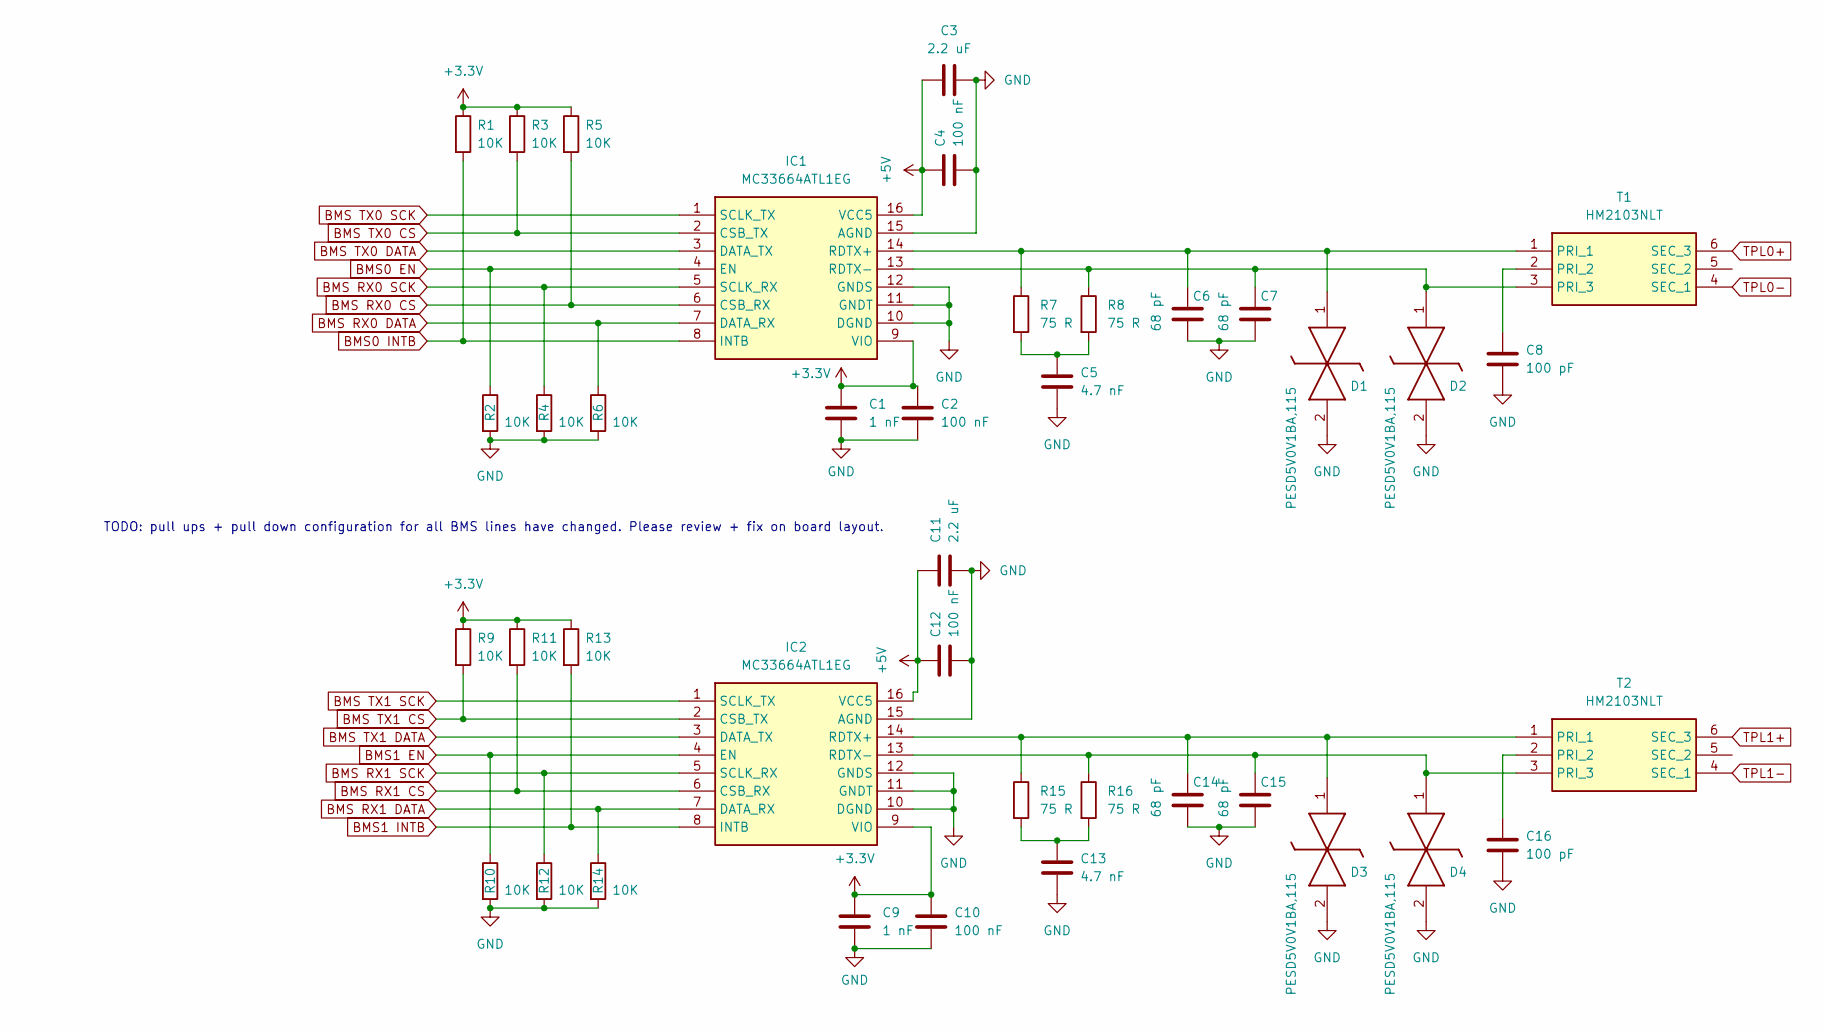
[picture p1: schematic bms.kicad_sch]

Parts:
C1, C9: 1 nF; C_0402_1005Metric
C2, C4, C10, C12: 100 nF; C_0402_1005Metric
C3, C11: 2.2 uF; C_0805_2012Metric
C5, C13: 4.7 nF; C_0402_1005Metric
C6, C7, C14, C15: 68 pF; C_0402_1005Metric
C8, C16: 100 pF; C_0402_1005Metric
D1, D2, D3, D4: PESD5V0V1BA,115; SOD2512X110N; Mouser Part Number 771-PESD5V0V1771-BA
IC1, IC2: MC33664ATL1EG; SOIC127P600X175-16N; Mouser Part Number 841-MC33664ATL1EG
R1, R2, R3, R4, R5, R6, R9, R10, R11, R12, R13, R14: 10K; C_0402_1005Metric
R7, R8, R15, R16: 75 R; C_0603_1608Metric
T1, T2: HM2103NLT; SOP254P940X572-6N; Mouser Part Number 673-HM2103NLT

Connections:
+3.3V: C1.1, C2.1, C9.1, C10.1, IC1.9 (VIO), IC2.9 (VIO), R1.1, R3.1, R5.1, R9.1, R11.1, R13.1; also elsewhere on the board
+5V: C3.1, C4.1, C11.1, C12.1, IC1.16 (VCC5), IC2.16 (VCC5); also elsewhere on the board
BMS0 EN: IC1.4 (EN), R2.1
BMS0 INTB: IC1.8 (INTB), R1.2
BMS1 EN: IC2.4 (EN), R10.1
BMS1 INTB: IC2.8 (INTB), R13.2
BMS RX0 CS: IC1.6 (CSB_RX), R5.2
BMS RX0 DATA: IC1.7 (DATA_RX), R6.1
BMS RX0 SCK: IC1.5 (SCLK_RX), R4.1
BMS RX1 CS: IC2.6 (CSB_RX), R11.2
BMS RX1 DATA: IC2.7 (DATA_RX), R14.1
BMS RX1 SCK: IC2.5 (SCLK_RX), R12.1
BMS TX0 CS: IC1.2 (CSB_TX), R3.2
BMS TX0 DATA: IC1.3 (DATA_TX)
BMS TX0 SCK: IC1.1 (SCLK_TX)
BMS TX1 CS: IC2.2 (CSB_TX), R9.2
BMS TX1 DATA: IC2.3 (DATA_TX)
BMS TX1 SCK: IC2.1 (SCLK_TX)
GND: C1.2, C2.2, C3.2, C4.2, C5.2, C6.2, C7.2, C8.2, C9.2, C10.2, C11.2, C12.2, C13.2, C14.2, C15.2, C16.2, D1.2 (K2), D2.2 (K2), D3.2 (K2), D4.2 (K2), IC1.10 (DGND), IC1.11 (GNDT), IC1.12 (GNDS), IC1.15 (AGND), IC2.10 (DGND), IC2.11 (GNDT), IC2.12 (GNDS), IC2.15 (AGND), R2.2, R4.2, R6.2, R10.2, R12.2, R14.2; also elsewhere on the board
unnamed: C5.1, R7.2, R8.2
unnamed: C13.1, R15.2, R16.2
unnamed: C6.1, D1.1 (K1), IC1.14 (RDTX+), R7.1, T1.1 (PRI_1)
unnamed: C7.1, D2.1 (K1), IC1.13 (RDTX-), R8.1, T1.3 (PRI_3)
unnamed: C14.1, D3.1 (K1), IC2.14 (RDTX+), R15.1, T2.1 (PRI_1)
unnamed: C15.1, D4.1 (K1), IC2.13 (RDTX-), R16.1, T2.3 (PRI_3)
unnamed: C8.1, T1.2 (PRI_2)
unnamed: C16.1, T2.2 (PRI_2)
TPL0+: T1.6 (SEC_3); also elsewhere on the board
TPL0-: T1.4 (SEC_1); also elsewhere on the board
TPL1+: T2.6 (SEC_3); also elsewhere on the board
TPL1-: T2.4 (SEC_1); also elsewhere on the board

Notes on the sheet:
TODO: pull ups + pull down configuration for all BMS lines have changed. Please review + fix on board layout.

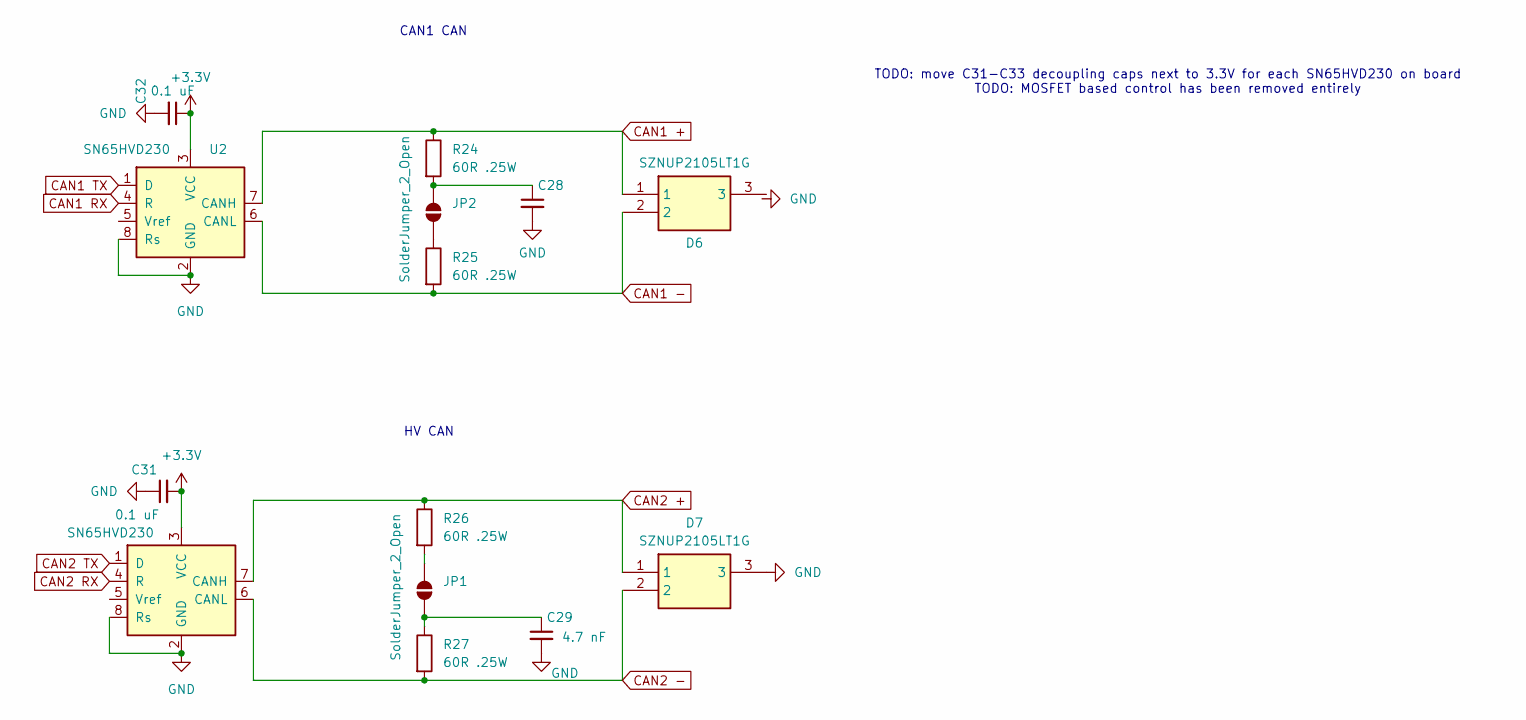
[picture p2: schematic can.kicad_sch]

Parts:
C28, C29: 4.7 nF; C_0402_1005Metric
C31, C32: 0.1 uF; C_0402_1005Metric
D6, D7: SZNUP2105LT1G; SOT-23_ONS; Mouser Part Number 863-SZNUP2105LT1G
JP1, JP2: SolderJumper_2_Open; SolderJumper-2_P1.3mm_Open_RoundedPad1.0x1.5mm
R24, R25, R26, R27: 60R .25W; R_0603_1608Metric
U2, U3: SN65HVD230; SOIC-8_3.9x4.9mm_P1.27mm

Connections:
+3.3V: C31.2, C32.1, U2.3 (VCC), U3.3 (VCC); also elsewhere on the board
CAN1 +: D6.1, R24.1, U2.7 (CANH); also elsewhere on the board
CAN1 -: D6.2, R25.2, U2.6 (CANL); also elsewhere on the board
CAN1 RX: U2.4 (R); also elsewhere on the board
CAN1 TX: U2.1 (D); also elsewhere on the board
CAN2 +: D7.1, R26.1, U3.7 (CANH); also elsewhere on the board
CAN2 -: D7.2, R27.2, U3.6 (CANL); also elsewhere on the board
CAN2 RX: U3.4 (R); also elsewhere on the board
CAN2 TX: U3.1 (D); also elsewhere on the board
GND: C28.2, C29.2, C31.1, C32.2, D7.3, U2.2 (GND), U2.8 (Rs), U3.2 (GND), U3.8 (Rs); also elsewhere on the board
unnamed: C29.1, JP1.1 (A), R27.1
unnamed: JP1.2 (B), R26.2
unnamed: JP2.1 (A), R25.1
unnamed: C28.1, JP2.2 (B), R24.2

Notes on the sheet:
CAN1 CAN
HV CAN
TODO: move C31-C33 decoupling caps next to 3.3V for each SN65HVD230 on board TODO: MOSFET based control has been removed entirely

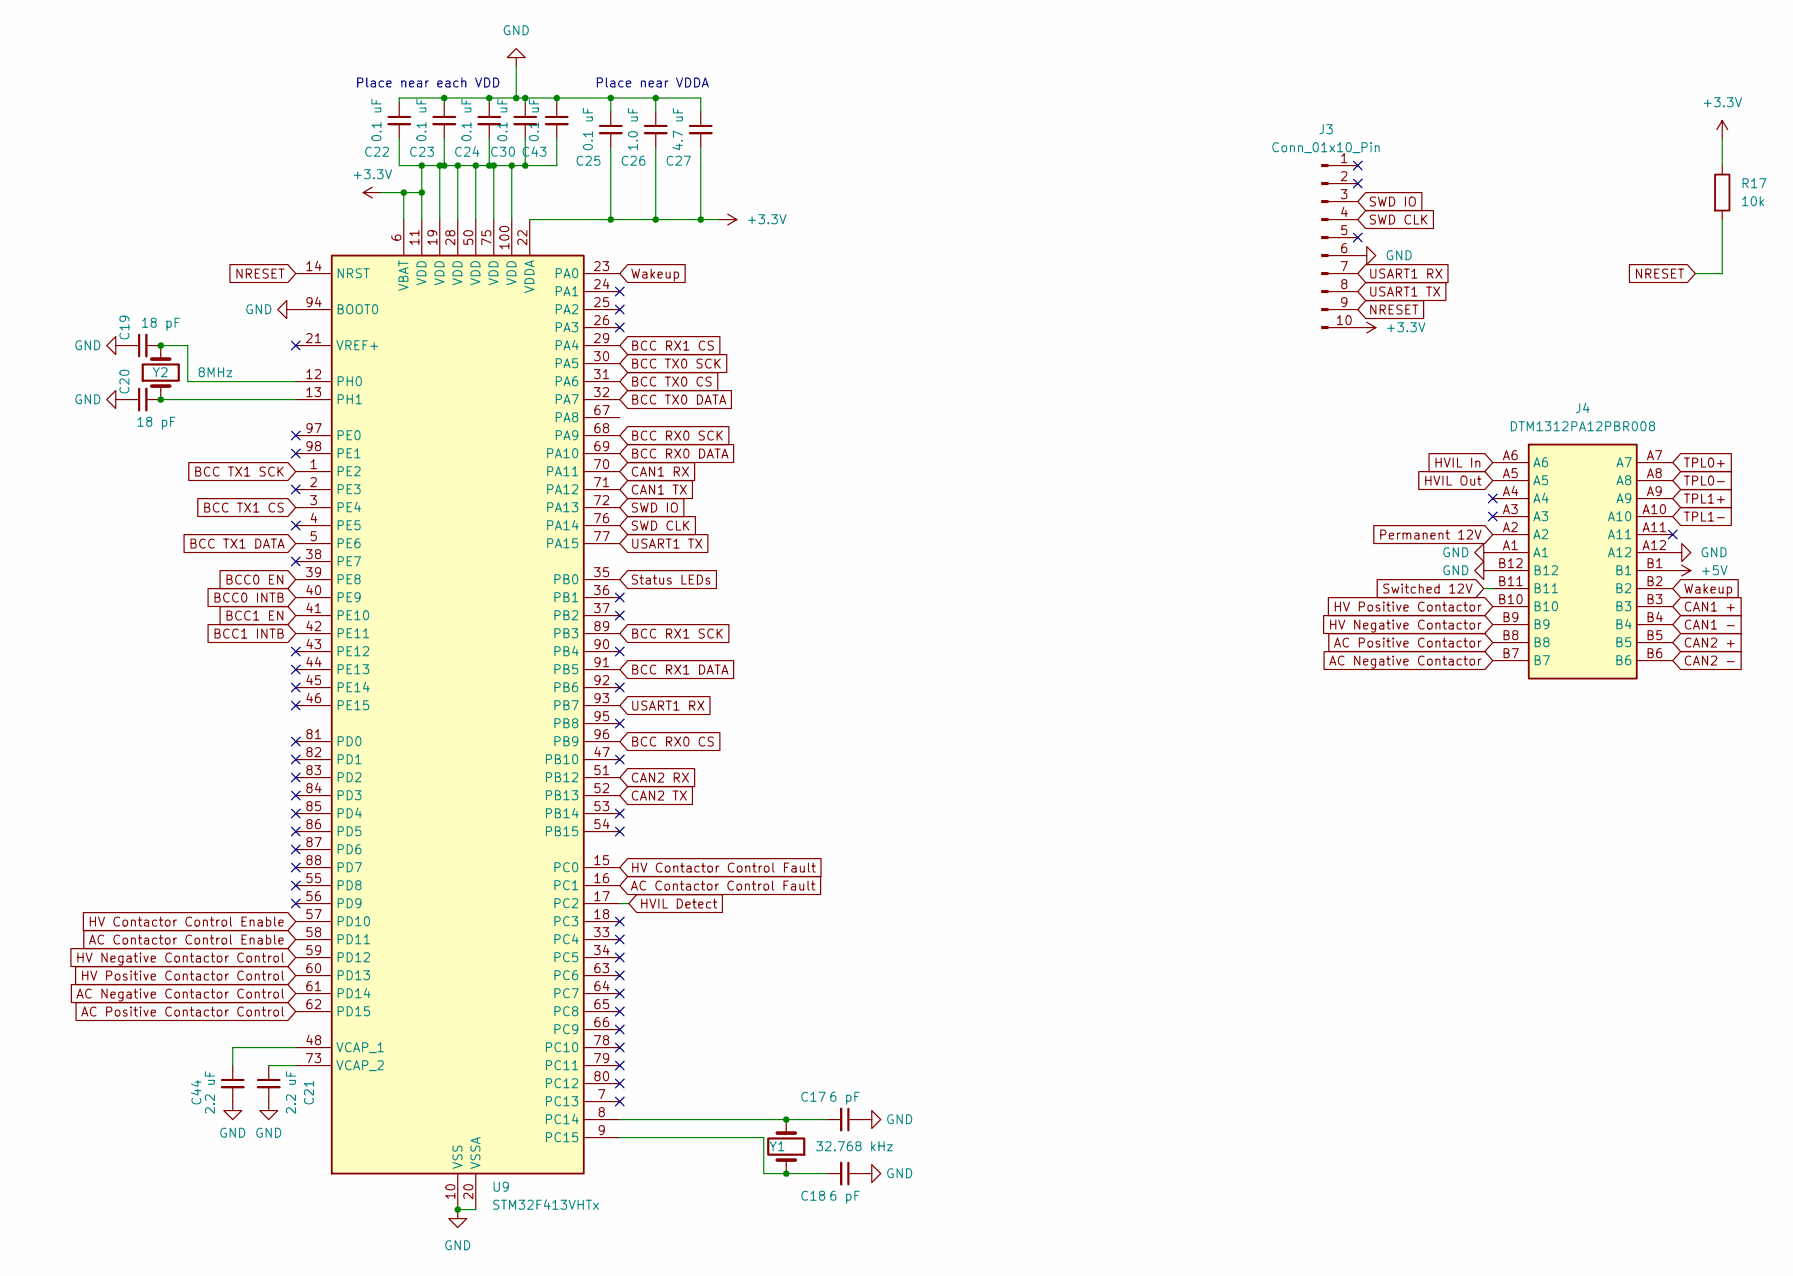
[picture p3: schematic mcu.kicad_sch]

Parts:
C17, C18: 6 pF; C_0402_1005Metric
C19, C20: 18 pF; C_0402_1005Metric
C21, C44: 2.2 uF; C_0805_2012Metric
C22, C23, C24, C25, C30, C43: 0.1 uF; C_0402_1005Metric
C26: 1.0 uF; C_0402_1005Metric
C27: 4.7 uF; C_0805_2012Metric
J3: Conn_01x10_Pin; ST-Link MINIV3 BTB
J4: DTM1312PA12PBR008; Mouser Part Number 571-TM1312PA12PBR008
R17: 10k; R_0603_1608Metric
U9: STM32F413VHTx; LQFP-100_14x14mm_P0.5mm
Y1: 32.768 kHz; Crystal_SMD_3215-2Pin_3.2x1.5mm
Y2: 8MHz; Crystal_SMD_HC49-SD

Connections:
+3.3V: C22.2, C23.2, C24.2, C25.2, C26.2, C27.2, C30.2, C43.2, J3.10, R17.1, U9.6 (VBAT), U9.11 (VDD), U9.19 (VDD), U9.22 (VDDA), U9.28 (VDD), U9.50 (VDD), U9.75 (VDD), U9.100 (VDD); also elsewhere on the board
+5V: J4.B1; also elsewhere on the board
AC Contactor Control Enable: U9.58 (PD11); also elsewhere on the board
AC Contactor Control Fault: U9.16 (PC1); also elsewhere on the board
AC Negative Contactor: J4.B7; also elsewhere on the board
AC Negative Contactor Control: U9.61 (PD14); also elsewhere on the board
AC Positive Contactor: J4.B8; also elsewhere on the board
AC Positive Contactor Control: U9.62 (PD15); also elsewhere on the board
BCC0 EN: U9.39 (PE8)
BCC0 INTB: U9.40 (PE9)
BCC1 EN: U9.41 (PE10)
BCC1 INTB: U9.42 (PE11)
BCC RX0 CS: U9.96 (PB9)
BCC RX0 DATA: U9.69 (PA10)
BCC RX0 SCK: U9.68 (PA9)
BCC RX1 CS: U9.29 (PA4)
BCC RX1 DATA: U9.91 (PB5)
BCC RX1 SCK: U9.89 (PB3)
BCC TX0 CS: U9.31 (PA6)
BCC TX0 DATA: U9.32 (PA7)
BCC TX0 SCK: U9.30 (PA5)
BCC TX1 CS: U9.3 (PE4)
BCC TX1 DATA: U9.5 (PE6)
BCC TX1 SCK: U9.1 (PE2)
CAN1 +: J4.B3; also elsewhere on the board
CAN1 -: J4.B4; also elsewhere on the board
CAN1 RX: U9.70 (PA11); also elsewhere on the board
CAN1 TX: U9.71 (PA12); also elsewhere on the board
CAN2 +: J4.B5; also elsewhere on the board
CAN2 -: J4.B6; also elsewhere on the board
CAN2 RX: U9.51 (PB12); also elsewhere on the board
CAN2 TX: U9.52 (PB13); also elsewhere on the board
GND: C17.1, C18.1, C19.1, C20.1, C21.2, C22.1, C23.1, C24.1, C25.1, C26.1, C27.1, C30.1, C43.1, C44.2, J3.6, J4.A1, J4.A12, J4.B12, U9.10 (VSS), U9.20 (VSSA), U9.27 (VSS), U9.49 (VSS), U9.74 (VSS), U9.94 (BOOT0), U9.99 (VSS); also elsewhere on the board
HV Contactor Control Enable: U9.57 (PD10); also elsewhere on the board
HV Contactor Control Fault: U9.15 (PC0); also elsewhere on the board
HV Negative Contactor: J4.B9; also elsewhere on the board
HV Negative Contactor Control: U9.59 (PD12); also elsewhere on the board
HV Positive Contactor: J4.B10; also elsewhere on the board
HV Positive Contactor Control: U9.60 (PD13); also elsewhere on the board
HVIL Detect: U9.17 (PC2); also elsewhere on the board
HVIL In: J4.A6; also elsewhere on the board
NRESET: J3.9, R17.2, U9.14 (NRST)
unnamed: C17.2, U9.8 (PC14), Y1.2
unnamed: C18.2, U9.9 (PC15), Y1.1
unnamed: C19.2, U9.12 (PH0), Y2.2
unnamed: C20.2, U9.13 (PH1), Y2.1
unnamed: C44.1, U9.48 (VCAP_1)
unnamed: C21.1, U9.73 (VCAP_2)
Permanent 12V: J4.A2; also elsewhere on the board
SWD CLK: J3.4, U9.76 (PA14)
SWD IO: J3.3, U9.72 (PA13)
Status LEDs: U9.35 (PB0); also elsewhere on the board
Switched 12V: J4.B11; also elsewhere on the board
TPL0+: J4.A7; also elsewhere on the board
TPL0-: J4.A8; also elsewhere on the board
TPL1+: J4.A9; also elsewhere on the board
TPL1-: J4.A10; also elsewhere on the board
USART1 RX: J3.7, U9.93 (PB7)
USART1 TX: J3.8, U9.77 (PA15)
Wakeup: J4.B2, U9.23 (PA0)

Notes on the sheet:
Place near each VDD
Place near VDDA

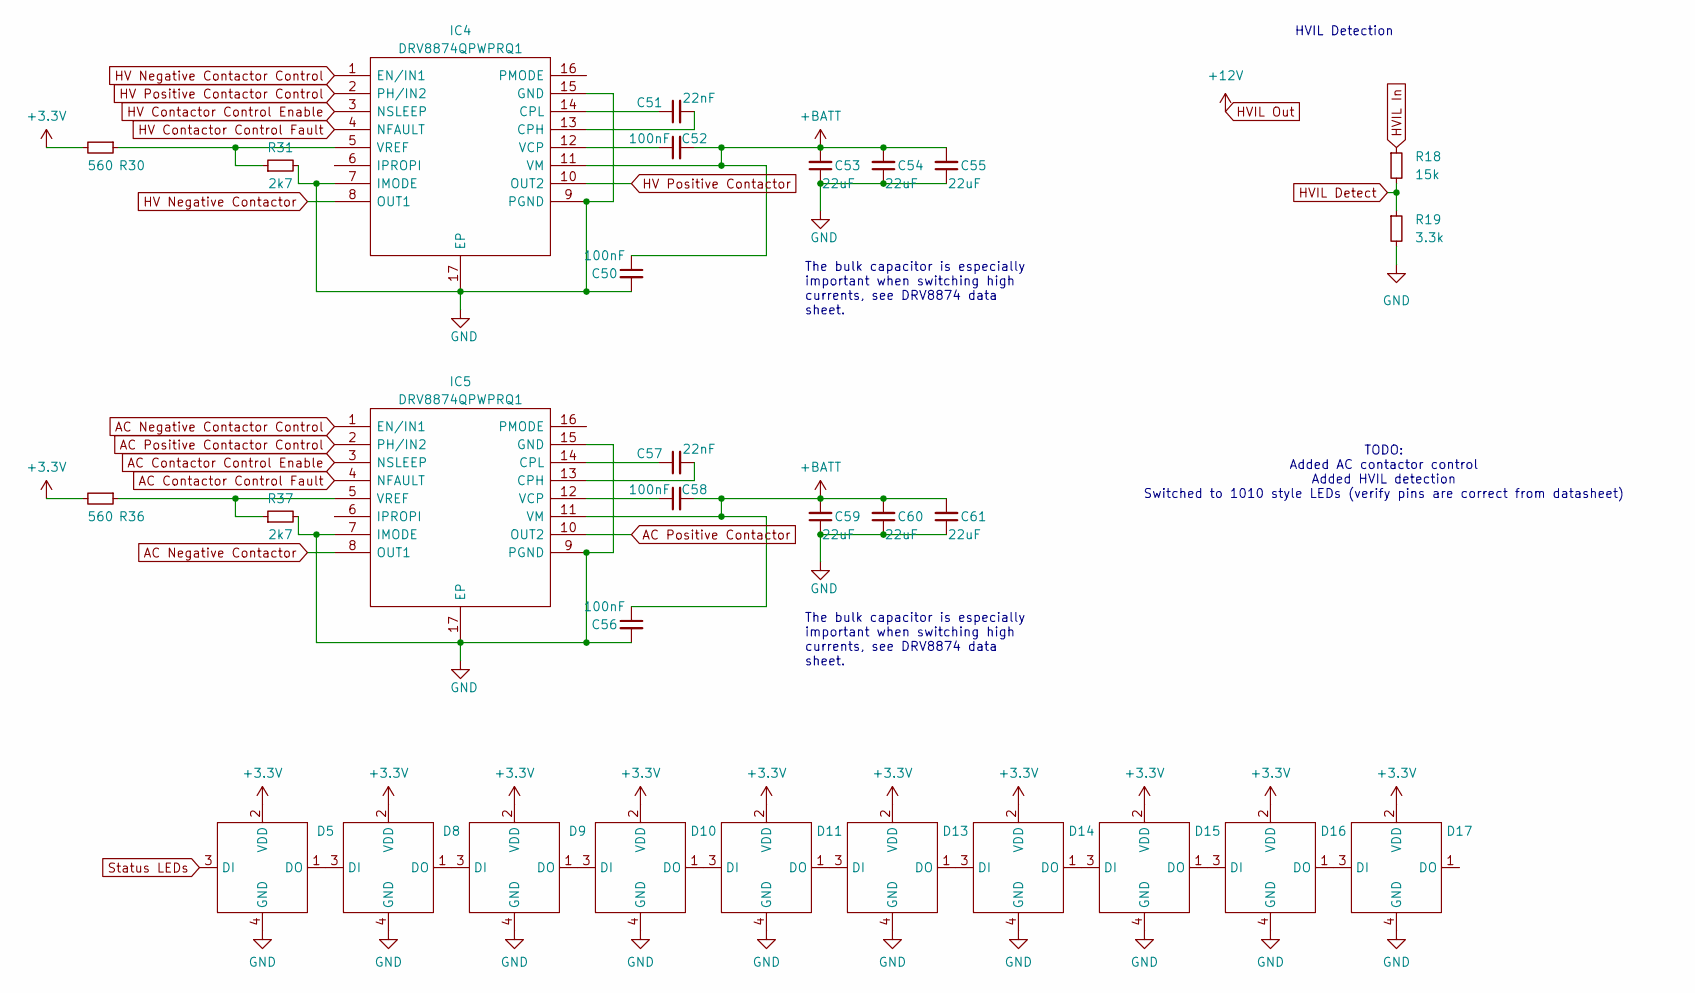
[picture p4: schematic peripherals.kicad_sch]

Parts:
C50, C52, C56, C58: 100nF; C_0805_2012Metric_Pad1.18x1.45mm_HandSolder; LCSC C49678
C51, C57: 22nF; C_0805_2012Metric_Pad1.18x1.45mm_HandSolder; LCSC C1729
C53, C54, C55, C59, C60, C61: 22uF; C_1210_3225Metric_Pad1.33x2.70mm_HandSolder; LCSC C12891
D5, D8, D9, D10, D11, D13, D14, D15, D16, D17: XL-1010RGBC-WS2812B
IC4, IC5: DRV8874QPWPRQ1; SOP65P640X120-17N; Mouser Part Number 595-DRV8874QPWPRQ1
R18: 15k; R_0402_1005Metric_Pad0.72x0.64mm_HandSolder
R19: 3.3k; R_0402_1005Metric_Pad0.72x0.64mm_HandSolder
R30, R36: 560; R_0805_2012Metric_Pad1.20x1.40mm_HandSolder; LCSC C28636
R31, R37: 2k7; R_0805_2012Metric_Pad1.20x1.40mm_HandSolder; LCSC C17530

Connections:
+3.3V: D5.2 (VDD), D8.2 (VDD), D9.2 (VDD), D10.2 (VDD), D11.2 (VDD), D13.2 (VDD), D14.2 (VDD), D15.2 (VDD), D16.2 (VDD), D17.2 (VDD), R30.2, R36.2; also elsewhere on the board
+BATT: C50.1, C52.2, C53.2, C54.2, C55.2, C56.1, C58.2, C59.2, C60.2, C61.2, IC4.11 (VM), IC5.11 (VM); also elsewhere on the board
AC Contactor Control Enable: IC5.3 (NSLEEP); also elsewhere on the board
AC Contactor Control Fault: IC5.4 (NFAULT); also elsewhere on the board
AC Negative Contactor: IC5.8 (OUT1); also elsewhere on the board
AC Negative Contactor Control: IC5.1 (EN/IN1); also elsewhere on the board
AC Positive Contactor: IC5.10 (OUT2); also elsewhere on the board
AC Positive Contactor Control: IC5.2 (PH/IN2); also elsewhere on the board
GND: C50.2, C53.1, C54.1, C55.1, C56.2, C59.1, C60.1, C61.1, D5.4 (GND), D8.4 (GND), D9.4 (GND), D10.4 (GND), D11.4 (GND), D13.4 (GND), D14.4 (GND), D15.4 (GND), D16.4 (GND), D17.4 (GND), IC4.7 (IMODE), IC4.9 (PGND), IC4.15 (GND), IC4.17 (EP), IC5.7 (IMODE), IC5.9 (PGND), IC5.15 (GND), IC5.17 (EP), R19.2, R31.2, R37.2; also elsewhere on the board
HV Contactor Control Enable: IC4.3 (NSLEEP); also elsewhere on the board
HV Contactor Control Fault: IC4.4 (NFAULT); also elsewhere on the board
HV Negative Contactor: IC4.8 (OUT1); also elsewhere on the board
HV Negative Contactor Control: IC4.1 (EN/IN1); also elsewhere on the board
HV Positive Contactor: IC4.10 (OUT2); also elsewhere on the board
HV Positive Contactor Control: IC4.2 (PH/IN2); also elsewhere on the board
HVIL Detect: R18.2, R19.1; also elsewhere on the board
HVIL In: R18.1; also elsewhere on the board
unnamed: D5.1 (DO), D8.3 (DI)
unnamed: D8.1 (DO), D9.3 (DI)
unnamed: D9.1 (DO), D10.3 (DI)
unnamed: D10.1 (DO), D11.3 (DI)
unnamed: D11.1 (DO), D13.3 (DI)
unnamed: D13.1 (DO), D14.3 (DI)
unnamed: D14.1 (DO), D15.3 (DI)
unnamed: D15.1 (DO), D16.3 (DI)
unnamed: D16.1 (DO), D17.3 (DI)
unnamed: C51.2, IC4.13 (CPH)
unnamed: C51.1, IC4.14 (CPL)
unnamed: C52.1, IC4.12 (VCP)
unnamed: IC4.5 (VREF), R30.1, R31.1
unnamed: C57.2, IC5.13 (CPH)
unnamed: C57.1, IC5.14 (CPL)
unnamed: C58.1, IC5.12 (VCP)
unnamed: IC5.5 (VREF), R36.1, R37.1
Status LEDs: D5.3 (DI); also elsewhere on the board

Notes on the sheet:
HVIL Detection
The bulk capacitor is especially important when switching high currents, see DRV8874 data sheet.
TODO: Added AC contactor control Added HVIL detection Switched to 1010 style LEDs (verify pins are correct from datasheet)

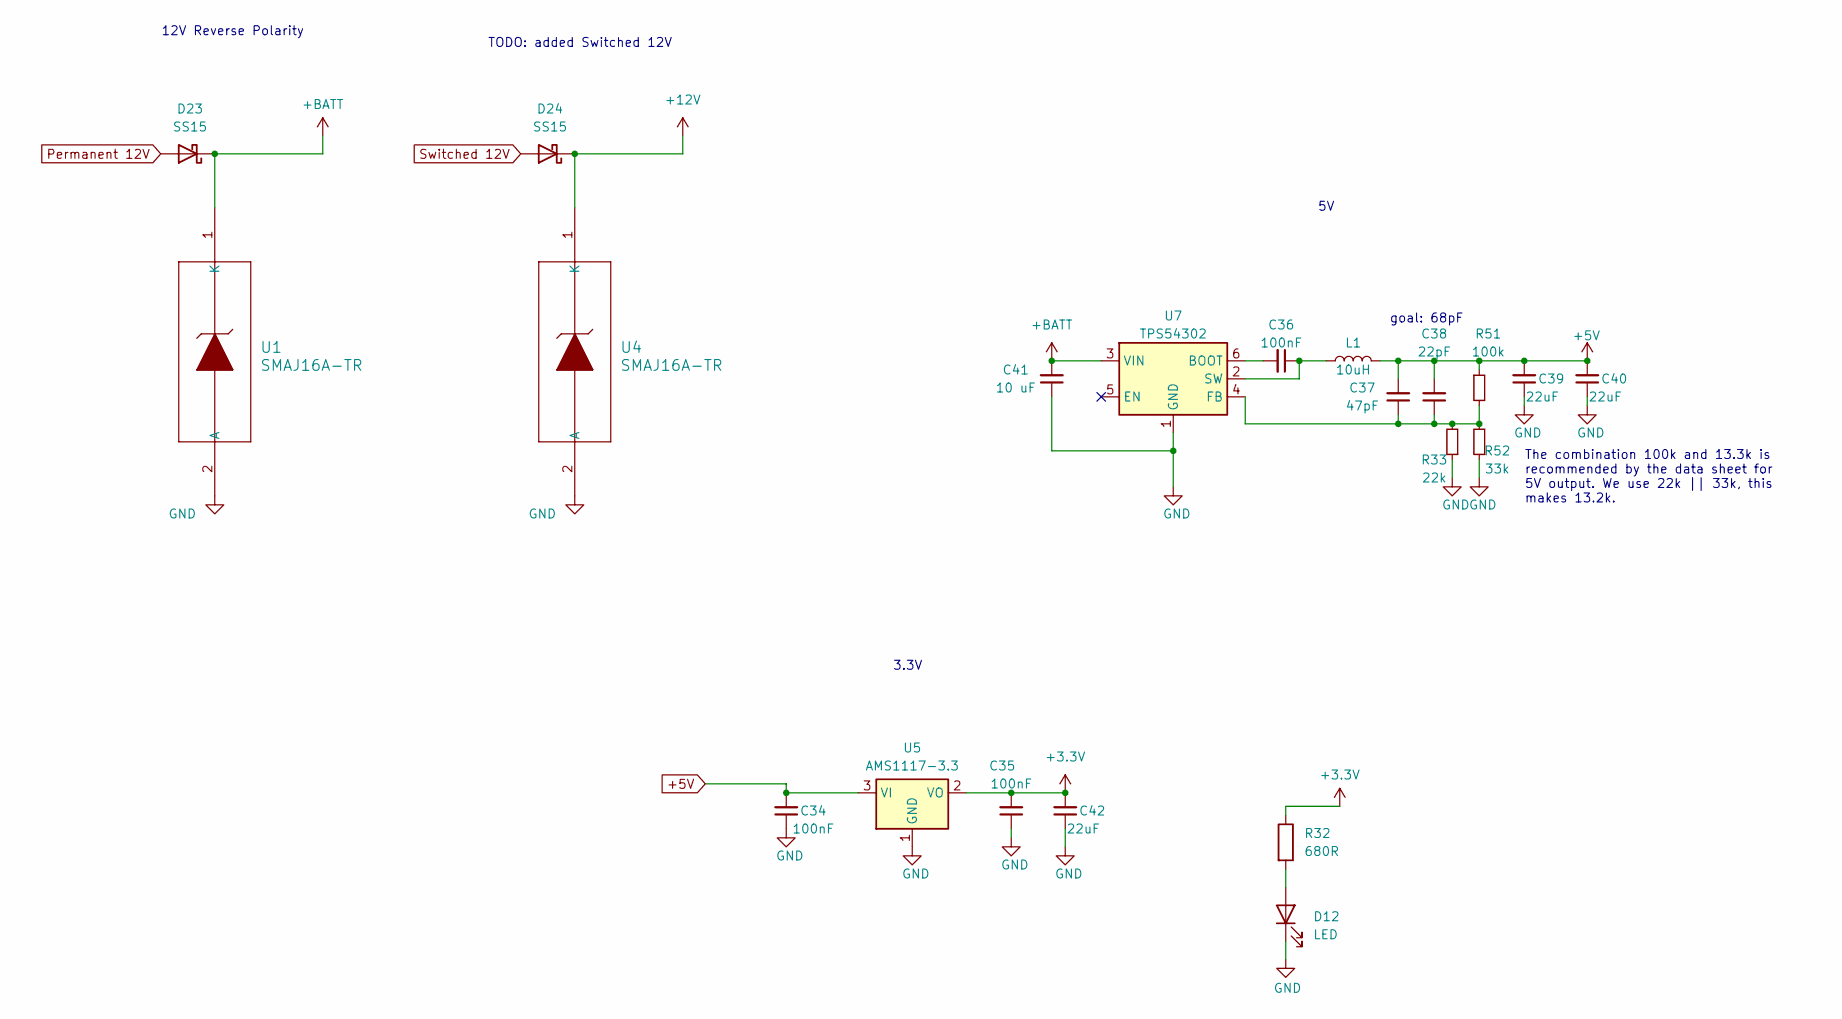
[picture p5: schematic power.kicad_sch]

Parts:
C34, C35, C36: 100nF; C_0805_2012Metric_Pad1.18x1.45mm_HandSolder; LCSC C49678
C37: 47pF; C_0805_2012Metric_Pad1.18x1.45mm_HandSolder; LCSC C14857
C38: 22pF; C_0805_2012Metric_Pad1.18x1.45mm_HandSolder; LCSC C1804
C39, C40, C42: 22uF; C_1210_3225Metric_Pad1.33x2.70mm_HandSolder; LCSC C12891
C41: 10 uF; C_0805_2012Metric_Pad1.18x1.45mm_HandSolder; LCSC C14857
D12: LED; D_0603_1608Metric
D23, D24: SS15; D_SMA
L1: 10uH; L_6.3x6.3_H3; LCSC C408412
R32: 680R; R_0603_1608Metric
R33: 22k; R_0805_2012Metric_Pad1.20x1.40mm_HandSolder; LCSC C17560
R51: 100k; R_0805_2012Metric_Pad1.20x1.40mm_HandSolder; LCSC C149504
R52: 33k; R_0805_2012Metric_Pad1.20x1.40mm_HandSolder; LCSC C17633
U1, U4: SMAJ16A-TR; SMA_UNI_STM; LCSC C908770
U5: AMS1117-3.3; SOT-223-3_TabPin2; LCSC C6186
U7: TPS54302; SOT-23-6; LCSC C311983

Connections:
+3.3V: C35.2, C42.2, R32.1, U5.2 (VO); also elsewhere on the board
+5V: C34.2, C37.2, C38.2, C39.2, C40.2, L1.2, R51.1, U5.3 (VI); also elsewhere on the board
+BATT: C41.2, D23.1 (K), U1.1 (K), U7.3 (VIN); also elsewhere on the board
GND: C34.1, C35.1, C39.1, C40.1, C41.1, C42.1, D12.1 (K), R33.1, R52.1, U1.2 (A), U4.2 (A), U5.1 (GND), U7.1 (GND); also elsewhere on the board
unnamed: D12.2 (A), R32.2
unnamed: C36.2, U7.6 (BOOT)
unnamed: C37.1, C38.1, R33.2, R51.2, R52.2, U7.4 (FB)
unnamed: C36.1, L1.1, U7.2 (SW)
Permanent 12V: D23.2 (A); also elsewhere on the board
Switched 12V: D24.2 (A); also elsewhere on the board

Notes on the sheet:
goal: 68pF
12V Reverse Polarity
3.3V
TODO: added Switched 12V
The combination 100k and 13.3k is recommended by the data sheet for 5V output. We use 22k || 33k, this makes 13.2k.

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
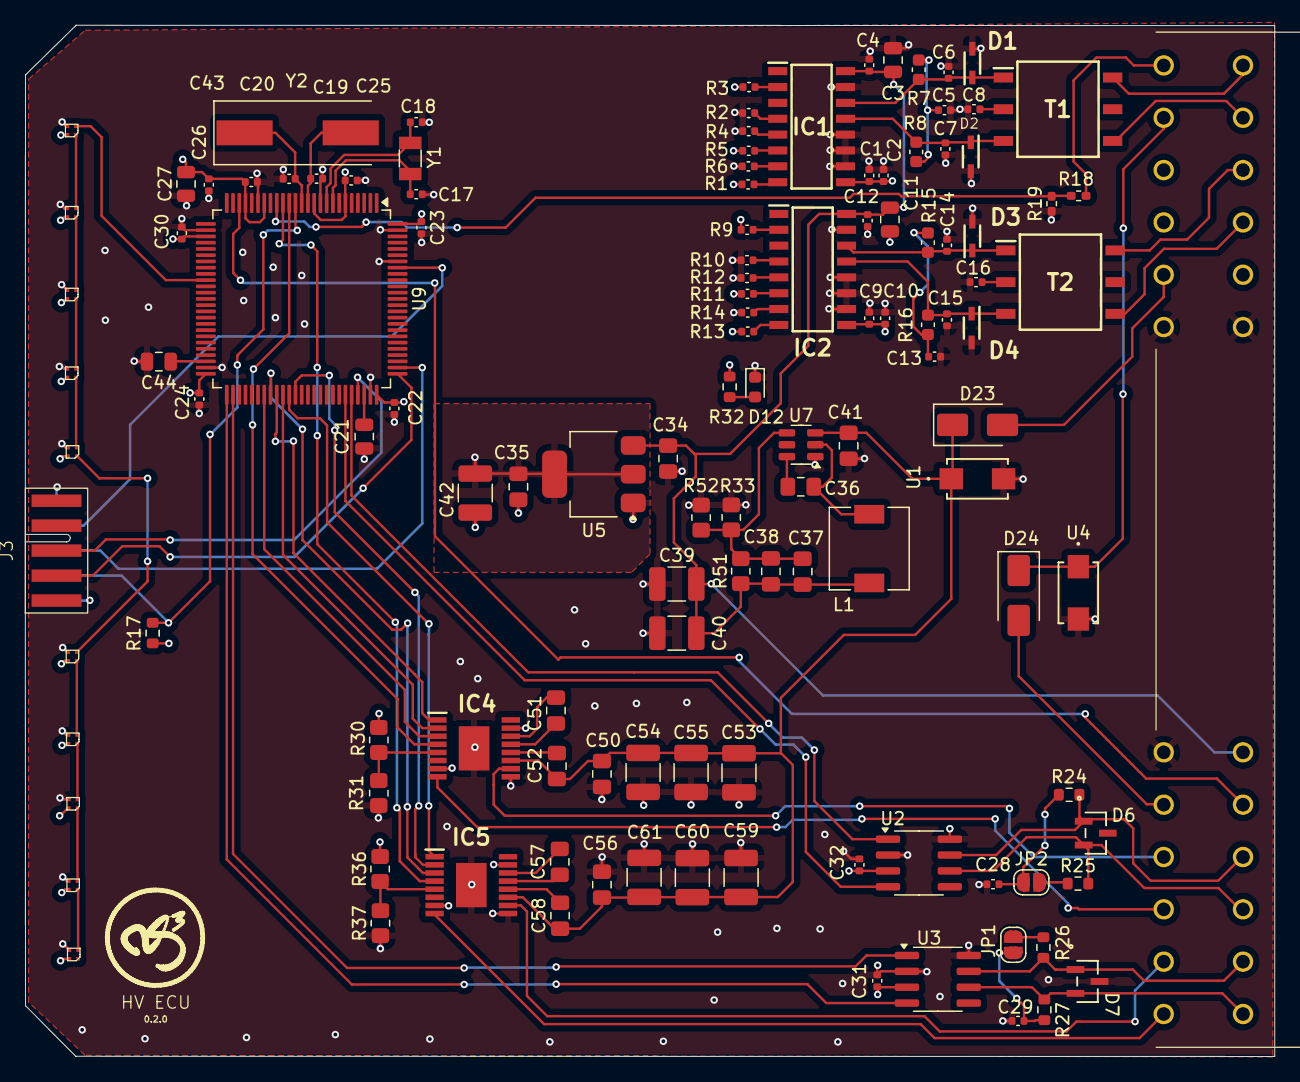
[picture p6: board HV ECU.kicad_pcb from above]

Board: 4 copper layers, 100.0 x 82.6 mm, 125 parts (0 on the bottom side), 91 nets.

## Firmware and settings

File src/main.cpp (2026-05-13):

/*
 * BMS Charging System for 6S2P Battery Packs
 *
 * Main application entry point and serial console interface.
 * See README.md for complete documentation, commands, and LED status indicators.
 */

#include "main.h"
#include <STM32FreeRTOS.h>
#include <Adafruit_NeoPixel.h>
#include <ArduinoJson.h>

Adafruit_NeoPixel strip = Adafruit_NeoPixel(STATUS_LED_COUNT, STATUS_LEDS, NEO_GRB + NEO_KHZ800);

// CAN bus instances
CANBus *m3_can = nullptr;   // M3 CAN for external communication
CANBus *hv_can = nullptr;   // HV CAN for IVT shunt and vehicle comms (500kbps)

// IVT controller
IVTShunt *ivt_shunt = nullptr;

// CHAdeMO controller (Foccci on M3/CP CAN)
CHAdeMOController *chademo = nullptr;

// libopeninv CanOpen SDO for BMS CAN communication
CanHardwareArduino *hv_can_hardware = nullptr;
CanMap *can_map = nullptr;
CanSdo *can_sdo = nullptr;

// HV CAN monitoring
bool hv_can_monitor_enabled = false;
uint32_t hv_can_frame_count = 0;

// M3 CAN test message generator
bool m3_can_test_enabled = false;
uint32_t m3_can_test_interval_ms = 1000;  // Default 1Hz
uint32_t m3_can_test_count = 0;

QueueHandle_t m3_can_queue = nullptr;
QueueHandle_t hv_can_queue = nullptr;

#define CAN_QUEUE_LENGTH 32  // Buffer up to 32 messages per bus

// BMS Configuration - will be populated from parameters in setup()
BatteryCellControllerConfig bcc0_config;
BatteryCellControllerConfig bcc1_config;

BatteryManagementSystem *bms;

// Pre-generated parameter JSON for web interface
String parameterJson;

// Forward declarations
void send_parameter_json();
void dump_bcc_config(BatteryManagementSystem *bms);

// Direct data source callback for JSON transfer - returns byte at offset or -1 if out of range
int get_json_byte(uint32_t offset) {
  if (offset >= parameterJson.length()) {
    return -1;  // End of data
  }
  return (int)(uint8_t)parameterJson[offset];
}

// CAN RX polling task - reads from hardware and puts messages into queues
void can_rx_task(void *pvParameters) {
  CAN_FRAME frame;
  static uint32_t last_debug = 0;
  static uint32_t m3_read_count = 0;
  static uint32_t hv_read_count = 0;

  while (true)  {
    // Poll M3 CAN bus
    if (m3_can && m3_can->available()) {
      while (m3_can->read(frame)) {
        m3_read_count++;
        xQueueSend(m3_can_queue, &frame, 0);
      }
    }

    // Poll HV CAN bus
    if (hv_can && hv_can->available()) {
      while (hv_can->read(frame)) {
        hv_read_count++;
        Serial.printf("HV RX: 0x%03X [%d] %02X %02X %02X %02X %02X %02X %02X %02X\r\n",
                      frame.id, frame.length,
                      frame.data.uint8[0], frame.data.uint8[1], frame.data.uint8[2], frame.data.uint8[3],
                      frame.data.uint8[4], frame.data.uint8[5], frame.data.uint8[6], frame.data.uint8[7]);

        // Put frame in queue
        xQueueSend(hv_can_queue, &frame, 0);
      }
    }

    // Poll every 1ms (1000 Hz)
    vTaskDelay(pdMS_TO_TICKS(1));
  }
}

// IVT processing task - processes messages from HV CAN queue
void ivt_process_task(void *pvParameters) {
  CAN_FRAME frame;

  while (true) {
    // TODO: replace with HV can when the hardware is fixed
    // Wait for M3 CAN message (block for up to 10ms)
    if (xQueueReceive(m3_can_queue, &frame, pdMS_TO_TICKS(10)) == pdTRUE) {
      // Process all messages through CanOpen SDO handler first
      if (hv_can_hardware && can_sdo) {
        uint32_t data[2];
        memcpy(data, frame.data.uint8, 8);
        hv_can_hardware->HandleRx(frame.id, data, frame.length);
      }

      // Check if message is for IVT (0x521-0x528 or 0x511)
      if ((frame.id >= 0x521 && frame.id <= 0x528) || frame.id == 0x511) {
        if (ivt_shunt) {
          ivt_shunt->process_can_frame(&frame);
        }
      }
      // Check if message is for CHAdeMO (0x100, 0x102, 0x108, 0x109)
      else if (frame.id == 0x100 || frame.id == 0x102 || frame.id == 0x108 || frame.id == 0x109) {
        if (chademo) {
          chademo->process_can_message(&frame);
        }
      }
    }
  }
}

// Generate parameter JSON once at startup
void build_parameter_json() {
  JsonDocument doc;

  for (int i = 0; i < Param::PARAM_LAST; i++) {
    const Param::Attributes* attr = Param::GetAttrib((Param::PARAM_NUM)i);
    if (!attr) continue;

    JsonObject param = doc[attr->name].to<JsonObject>();
    param["unit"] = attr->unit;
    param["category"] = attr->category;
    // Use native float values directly (no conversion needed)
    param["minimum"] = attr->min;
    param["maximum"] = attr->max;
    param["default"] = attr->def;
    param["id"] = attr->id;  // Add parameter ID for SDO access
    param["isparam"] = (Param::GetType((Param::PARAM_NUM)i) == Param::TYPE_PARAM) ? 1 : 0;
    
    // Version is already stored as major.minor float
    if (strcmp(attr->name, "version") == 0) {
      param["value"] = Param::GetFloat((Param::PARAM_NUM)i);
    }
    // For other spot values, include current value
    else if (Param::GetType((Param::PARAM_NUM)i) == Param::TYPE_SPOTVALUE) {
      param["value"] = Param::GetFloat((Param::PARAM_NUM)i);
    }
  }

  serializeJson(doc, parameterJson);
  Serial.printf("Generated parameter JSON (%d bytes)\r\n", parameterJson.length());
  
  // Update CanSdo with actual JSON size
  if (can_sdo != nullptr) {
    can_sdo->SetJsonSize(parameterJson.length());
  }
}

// Send stored JSON to web interface
void send_parameter_json() {
  if (!can_sdo || parameterJson.length() == 0) return;

  // Send all data without delays - the print buffer and timeout mechanism will handle flow control
  for (unsigned int i = 0; i < parameterJson.length(); i++) {
    can_sdo->PutChar(parameterJson[i]);
  }
}

// CanOpen periodic task - sends mapped CAN messages
void canopen_periodic_task(void *pvParameters) {
  Serial.println("CanOpen Periodic Task: Started");

  while (true) {
    // Send all mapped CAN messages
    if (can_map != nullptr) {
      can_map->SendAll();
    }

    // Trigger SDO timeout handling
    if (can_sdo != nullptr) {
      can_sdo->TriggerTimeout(10);  // 10ms period
    }

    // Periodic delay (100Hz - 10ms for responsive SDO communication)
    vTaskDelay(pdMS_TO_TICKS(10));
  }
}

// Serial console task for user commands
void console_task(void *pvParameters) {
  Serial.println("\n=== BMS Serial Console ===");
  Serial.println("Type 'help' for available commands");
  Serial.println();

  String inputBuffer = "";

  while (true) {
    // Check for available serial data
    while (Serial.available() > 0) {
      char c = Serial.read();

      if (c == '\n' || c == '\r') {
        if (inputBuffer.length() > 0) {
          // Process command
          inputBuffer.trim();
          inputBuffer.toLowerCase();

          if (inputBuffer == "help") {
            bool bcc0_ok = bms->is_bcc0_initialized();
            bool bcc1_ok = bms->is_bcc1_initialized();
            bool any_bcc_ok = bcc0_ok || bcc1_ok;

            Serial.println("\n=== Available Commands ===");
            Serial.println("help                  - Show this help message");
            Serial.println("status                - Show current BMS status");
            Serial.println("bcc                   - Show BCC status");
            Serial.println("ivt                   - Show IVT shunt status");
            Serial.println("chademo               - Show CHAdeMO status");
            Serial.println("hv                    - Show HV system status");
            Serial.println("hv can monitor        - Show HV CAN monitoring status");
            Serial.println("hv can monitor on     - Enable HV CAN traffic monitoring");
            Serial.println("hv can monitor off    - Disable HV CAN traffic monitoring");
            Serial.println("m3 can send <id> <b0> <b1> ... <b7>");
            Serial.println("                      - Send CAN message on M3 bus (hex values)");
            Serial.println("m3 can test           - Show test generator status");
            Serial.println("m3 can test on        - Enable periodic test messages (1Hz IVT)");
            Serial.println("m3 can test off       - Disable test messages");
            Serial.println("m3 can test rate <ms> - Set test message interval (ms)");
            Serial.println("reboot                - Software reset (restart application)");
            Serial.println();

            if (any_bcc_ok) {
              Serial.println("=== BCC (Battery Cell Controller) Commands ===");
              Serial.println("bcc start             - Start charging");
              Serial.println("bcc stop              - Stop charging");
              Serial.println("bcc balance           - Force cell balancing");
              Serial.println("bcc config dump       - Dump pack configuration registers");
              Serial.println("bcc voltages [summary]");
              Serial.println("                      - Show module voltage summary");
              Serial.println("bcc voltages <module#>");
              Serial.println("                      - Show detailed voltages for specific module (0-15)");
              Serial.println("bcc faults            - Show fault status");
              Serial.println("bcc config            - Show charging configuration");
              Serial.println("bcc dump              - Dump all BCC registers and fuse mirror");
              Serial.println("bcc sleep             - Put BCC into low-power sleep mode");
              Serial.println("bcc wakeup            - Wake BCC from sleep mode");
              Serial.println("bcc set target <voltage>");
              Serial.println("                      - Set target cell voltage (V)");
              Serial.println("bcc set balance_th <mv>");
              Serial.println("                      - Set balance threshold (mV)");
              Serial.println("bcc set balance_tgt <mv>");
              Serial.println("                      - Set balance target (mV)");
              Serial.println("bcc set interval <ms> - Set measurement interval (ms)");
              Serial.println();
            }

            Serial.println("=== CHAdeMO (Foccci) Commands ===");
            Serial.println("chademo start <volts> <amps>");
            Serial.println("                      - Start CHAdeMO charge session");
            Serial.println("chademo stop          - Stop CHAdeMO charge session");
            Serial.println("chademo limits <v> <a>");
            Serial.println("                      - Set EVSE capabilities (max voltage/current)");
            Serial.println();

            Serial.println("=== CanOpen SDO Commands ===");
            Serial.println("can sdo read <nodeId> <index> <subIndex>");
            Serial.println("                      - Read SDO parameter from remote node");
            Serial.println("can sdo write <nodeId> <index> <subIndex> <value>");
            Serial.println("                      - Write SDO parameter to remote node");
            Serial.println("can map save          - Save CAN mappings to flash");
            Serial.println("can node <id>         - Set local CAN node ID");
            Serial.println();
          }
          else if (inputBuffer == "status") {
            BMS_State state = bms->get_state();
            const char* state_str[] = {"Initialization", "Idle", "Charging", "Cell Balancing", "Cooldown", "Sleep", "Error"};
            Serial.println("\n=== BMS Status ===");
            Serial.printf("State: %s\r\n", state_str[state]);
            Serial.println();
            
            // Show spot values being transmitted
            Serial.println("=== Spot Values (being transmitted on CAN) ===");
            Serial.printf("Pack Voltage: %.2f V\r\n", Param::GetFloat(Param::packVoltage));
            Serial.printf("Pack Current: %.2f A\r\n", Param::GetFloat(Param::packCurrent));
            Serial.printf("Max Cell: %d mV\r\n", Param::GetInt(Param::maxCellVolt));
            Serial.printf("Min Cell: %d mV\r\n", Param::GetInt(Param::minCellVolt));
            Serial.printf("Cell Diff: %d mV\r\n", Param::GetInt(Param::cellVoltDiff));
            Serial.printf("SOC: %d %%\r\n", Param::GetInt(Param::soc));
            Serial.printf("BMS State: %d\r\n", Param::GetInt(Param::bmsState));
            Serial.printf("HV State: %d\r\n", Param::GetInt(Param::hvState));
            Serial.printf("Safe Charge Current: %d A\r\n", Param::GetInt(Param::safeChargeCurrent));
            Serial.println();
          }
          else if (inputBuffer == "bcc") {
            Serial.println("\n=== BCC Status ===");
            Serial.printf("BCC0: %s\r\n", bms->is_bcc0_initialized() ? "Initialized" : "NOT INITIALIZED");
            if (bms->is_bcc1_enabled()) {
              Serial.printf("BCC1: %s\r\n", bms->is_bcc1_initialized() ? "Initialized" : "NOT INITIALIZED");
            } else {
              Serial.println("BCC1: Disabled");
            }
            Serial.println();
          }
          else if (inputBuffer == "bcc start") {
            if (!bms->is_bcc0_initialized() && !bms->is_bcc1_initialized()) {
              Serial.println("\nError: No BCC initialized. Cannot start charging.\n");
            } else {
              Serial.println();
              bms->start_charging();
              Serial.println();
            }
          }
          else if (inputBuffer == "bcc stop") {
            if (!bms->is_bcc0_initialized() && !bms->is_bcc1_initialized()) {
              Serial.println("\nError: No BCC initialized.\n");
            } else {
              Serial.println();
              bms->stop_charging();
              Serial.println();
            }
          }
          else if (inputBuffer == "bcc config dump") {
            if (!bms->is_bcc0_initialized() && !bms->is_bcc1_initialized()) {
              Serial.println("\nError: No BCC initialized. Cannot dump configuration.\n");
            } else {
              Serial.println("\nDumping BCC configuration...");
              Serial.println("Copy this configuration array to replace TAYCAN_CONFIG:\n");
              dump_bcc_config(bms);
              Serial.println();
            }
          }
          else if (inputBuffer == "bcc balance") {
            if (!bms->is_bcc0_initialized() && !bms->is_bcc1_initialized()) {
              Serial.println("\nError: No BCC initialized. Cannot force balancing.\n");
            } else {
              Serial.println();
              bms->force_balance_cells();
              Serial.println();
            }
          }
          else if (inputBuffer == "bcc voltages" || inputBuffer.startsWith("bcc voltages ")) {
            if (!bms->is_bcc0_initialized() && !bms->is_bcc1_initialized()) {
              Serial.println("\nError: No BCC initialized. Cannot read voltages.\n");
              continue;
            }

            uint32_t voltages_raw[BCC_MAX_CELLS];
            uint32_t voltages_filtered[BCC_MAX_CELLS];
            uint8_t count;
            bms->get_cell_voltages(voltages_raw, &count);
            bms->get_cell_voltages_filtered(voltages_filtered, &count);

            // Parse command - support "bcc voltages", "bcc voltages summary", or "bcc voltages <module#>"
            bool show_summary = (inputBuffer == "bcc voltages" || inputBuffer == "bcc voltages summary");
            int8_t module_num = -1;

            if (inputBuffer.startsWith("bcc voltages ") && inputBuffer != "bcc voltages summary") {
              String arg = inputBuffer.substring(13);
              module_num = arg.toInt();
            }

            Serial.println("\n=== Cell Voltages ===");

            // Display specific module if requested
            if (module_num >= 0) {
              uint8_t bcc0_device_count = bcc0_config.device_count;
              uint8_t cell_count = bcc0_config.cell_count;
              uint8_t bcc_chain = (module_num < bcc0_device_count) ? 0 : 1;
              uint8_t module_in_chain = module_num % bcc0_device_count;
              uint8_t start_cell = module_num * cell_count;
              uint8_t end_cell = start_cell + cell_count;

              if (start_cell >= count) {
                Serial.printf("Error: Module %d does not exist\r\n\n", module_num);
                continue;
              }

              Serial.printf("--- Module %d (BCC%d Device %d) ---\r\n", module_num, bcc_chain, module_in_chain);

              uint32_t module_voltage = 0;
              uint32_t min_v = voltages_filtered[start_cell];
              uint32_t max_v = voltages_filtered[start_cell];

              for (uint8_t i = start_cell; i < end_cell && i < count; i++) {
                Serial.printf("  Cell %d: %.4f V  (raw: %.4f V)\r\n",
                             (i % cell_count) + 1,
                             voltages_filtered[i] / 1000000.0f,
                             voltages_raw[i] / 1000000.0f);
                module_voltage += voltages_filtered[i];
                if (voltages_filtered[i] < min_v) min_v = voltages_filtered[i];
                if (voltages_filtered[i] > max_v) max_v = voltages_filtered[i];
              }

              float diff_mv = (max_v - min_v) / 1000.0f;
              Serial.printf("\nModule Voltage: %.3f V\r\n", module_voltage / 1000000.0f);
              Serial.printf("Min: %.4f V, Max: %.4f V, Diff: %.2f mV\r\n",
                           min_v / 1000000.0f, max_v / 1000000.0f, diff_mv);
              Serial.println();
            }
            // Display summary for all modules
            else if (show_summary) {
              uint8_t bcc0_device_count = bcc0_config.device_count;
              uint8_t cell_count = bcc0_config.cell_count;
              uint8_t bcc0_modules = bcc0_device_count;
              uint8_t total_modules = bcc0_device_count * (bms->is_bcc1_initialized() ? 2 : 1);

              uint32_t total_voltage = 0;
              uint32_t bcc0_voltage = 0;
              uint32_t bcc1_voltage = 0;

              // BCC0 modules
              if (bms->is_bcc0_initialized()) {
                Serial.println("--- BCC0 Module Summary ---");
                for (uint8_t mod = 0; mod < bcc0_modules; mod++) {
                  uint8_t start_cell = mod * cell_count;
                  uint8_t end_cell = start_cell + cell_count;

                  uint32_t module_voltage = 0;
                  uint32_t min_v = voltages_filtered[start_cell];
                  uint32_t max_v = voltages_filtered[start_cell];

                  for (uint8_t i = start_cell; i < end_cell && i < count; i++) {
                    module_voltage += voltages_filtered[i];
                    if (voltages_filtered[i] < min_v) min_v = voltages_filtered[i];
                    if (voltages_filtered[i] > max_v) max_v = voltages_filtered[i];
                  }

                  float diff_mv = (max_v - min_v) / 1000.0f;
                  Serial.printf("  Module %d: %.3f V  (Δ %.2f mV)\r\n",
                               mod, module_voltage / 1000000.0f, diff_mv);
                  bcc0_voltage += module_voltage;
                }
                Serial.printf("BCC0 Total: %.3f V\r\n\n", bcc0_voltage / 1000000.0f);
                total_voltage += bcc0_voltage;
              }

              // BCC1 modules
              if (bms->is_bcc1_initialized()) {
                Serial.println("--- BCC1 Module Summary ---");
                for (uint8_t mod = 0; mod < bcc0_modules; mod++) {
                  uint8_t module_num = mod + bcc0_modules;
                  uint8_t start_cell = module_num * cell_count;
                  uint8_t end_cell = start_cell + cell_count;

                  if (start_cell >= count) break;

                  uint32_t module_voltage = 0;
                  uint32_t min_v = voltages_filtered[start_cell];
                  uint32_t max_v = voltages_filtered[start_cell];

                  for (uint8_t i = start_cell; i < end_cell && i < count; i++) {
                    module_voltage += voltages_filtered[i];
                    if (voltages_filtered[i] < min_v) min_v = voltages_filtered[i];
                    if (voltages_filtered[i] > max_v) max_v = voltages_filtered[i];
                  }

                  float diff_mv = (max_v - min_v) / 1000.0f;
                  Serial.printf("  Module %d: %.3f V  (Δ %.2f mV)\r\n",
                               module_num, module_voltage / 1000000.0f, diff_mv);
                  bcc1_voltage += module_voltage;
                }
                Serial.printf("BCC1 Total: %.3f V\r\n\n", bcc1_voltage / 1000000.0f);
                total_voltage += bcc1_voltage;
              }

              // Overall statistics
              Serial.println("--- Overall Statistics ---");
              Serial.printf("Total Voltage (both chains): %.3f V\r\n", total_voltage / 1000000.0f);
              Serial.printf("Total Cell Count: %d\r\n", count);
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
void loop() {
  // Empty - FreeRTOS tasks run instead
}

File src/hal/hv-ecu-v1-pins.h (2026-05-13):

#pragma once

#define WAKEUP PA0

#define STATUS_LEDS PB0
#define STATUS_LED_COUNT 10

// DRV8874 H-bridge contactor driver control (PMODE floating = independent half-bridge mode)
// IN1 and IN2 independently control OUT1 and OUT2 for two separate contactors
#define HV_CONTACTOR_1_PIN PD12             // DRV8874 IN1 (controls OUT1, HIGH when energizing)
#define HV_CONTACTOR_2_PIN PD13             // DRV8874 IN2 (controls OUT2, HIGH when energizing)
#define HV_CONTACTOR_NSLEEP_PIN PD10        // DRV8874 nSLEEP (must be HIGH to operate)
#define HV_CONTACTOR_FAULT_PIN PC0         // DRV8874 nFAULT (Fault input, active LOW)

#define AC_CONTACTOR_1_PIN PD14             // DRV8874 IN1 (controls OUT1, HIGH when energizing)
#define AC_CONTACTOR_2_PIN PD15             // DRV8874 IN2 (controls OUT2, HIGH when energizing)
#define AC_CONTACTOR_NSLEEP_PIN PD11        // DRV8874 nSLEEP (must be HIGH to operate)
#define AC_CONTACTOR_FAULT_PIN PC1         // DRV8874 nFAULT (Fault input, active LOW)

#define HVIL_DETECT_PIN PC2 

// SPI1
#define BCC0_TX_SCK PA5
#define BCC0_TX_CS PA6
#define BCC0_TX_DATA PA7

// SPI2
#define BCC0_RX_SCK PA9
#define BCC0_RX_CS PB9
#define BCC0_RX_DATA PA10

#define BCC0_ENABLE PE8
#define BCC0_INTB PE9

// SPI4
#define BCC1_TX_SCK PE2
#define BCC1_TX_CS PE4
#define BCC1_TX_DATA PE6

// SPI3
#define BCC1_RX_SCK PB3_ALT1   // Force SPI3 instead of SPI1
#define BCC1_RX_CS PA4_ALT1    // SPI3_NSS (PA4 defaults to SPI1, need ALT1 for SPI3)
#define BCC1_RX_DATA PB5_ALT1

#define BCC1_ENABLE PE10
#define BCC1_INTB PE11

#define M3_CAN_RX PB12
#define M3_CAN_TX PB13

#define HV_CAN_RX PA11
#define HV_CAN_TX PA12

#define USART1_RX PB7
#define USART1_TX PA15_ALT1

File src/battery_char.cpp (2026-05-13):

/*
 * Battery Characterization Tool
 *
 * Reads GUID, configuration registers, and fuse mirror data from up to 8 batteries
 * on each BCC chain (BCC0 and BCC1) and outputs to CSV format.
 *
 * Usage:
 *   1. Build with: pio run -e battery-char
 *   2. Upload with: pio run -e battery-char -t upload
 *   3. Monitor with: pio device monitor
 *   4. Save output to file by redirecting serial output
 */

#include "Arduino.h"
#include "SPI.h"
#include "TPLSPI.h"
#include "BatteryCellController.h"
#include "bcc/bcc_config.h"
#include "hal/dma_config.h"
#include "hal/hv-ecu-v1-pins.h"

#include "debug_serial.h"

// Configuration
#define MAX_DEVICES 8
#define CELL_COUNT 6

// Global objects
TPLSPI *tpl0, *tpl1;
BatteryCellController *bcc0, *bcc1;
SPIClass *bcc0_tx_spi, *bcc0_rx_spi;
SPIClass *bcc1_tx_spi, *bcc1_rx_spi;
bcc_device_t devices_0[MAX_DEVICES];
bcc_device_t devices_1[MAX_DEVICES];

void print_csv_header() {
  debug_println("\n=== Battery Characterization Data ===");
  debug_println("CSV Format: BCC,CID,Field,Address,Value,Description");
  debug_println("---");
}

void dump_device_guid(uint8_t bcc_num, bcc_cid_t cid, BatteryCellController *bcc) {
  uint64_t guid;
  bcc_status_t error = bcc->read_guid(cid, &guid);

  if (error == BCC_STATUS_SUCCESS) {
    debug_printf("%d,%d,GUID,N/A,0x%02X%04X%04X,Device GUID\r\n",
                 bcc_num, cid,
                 (uint16_t)((guid >> 32) & 0x001FU),
                 (uint16_t)((guid >> 16) & 0xFFFFU),
                 (uint16_t)(guid & 0xFFFFU));
  } else {
    debug_printf("%d,%d,GUID,N/A,ERROR_%d,Failed to read GUID\r\n",
                 bcc_num, cid, error);
  }
}

void dump_device_init_register(uint8_t bcc_num, bcc_cid_t cid, BatteryCellController *bcc) {
  uint16_t regVal;
  bcc_status_t error = bcc->read_register(cid, BCC_REG_INIT_ADDR, 1U, &regVal);

  if (error == BCC_STATUS_SUCCESS) {
    debug_printf("%d,%d,INIT,0x%04X,0x%04X,Initialization register\r\n",
                 bcc_num, cid, BCC_REG_INIT_ADDR, regVal);
  } else {
    debug_printf("%d,%d,INIT,0x%04X,ERROR_%d,Failed to read\r\n",
                 bcc_num, cid, BCC_REG_INIT_ADDR, error);
  }
}

void dump_device_config_registers(uint8_t bcc_num, bcc_cid_t cid, BatteryCellController *bcc, bcc_device_t device_type) {
  uint16_t regVal;

  if (device_type == BCC_DEVICE_MC33771) {
    for (uint8_t i = 0; i < REG_CONF_CNT_MC33771; i++) {
      bcc_status_t error = bcc->read_register(cid, BCC_REGISTERS_DATA_MC33771[i].address, 1U, &regVal);

      if (error == BCC_STATUS_SUCCESS) {
        debug_printf("%d,%d,%s,0x%04X,0x%04X,Configuration register\r\n",
                     bcc_num, cid,
                     BCC_REGISTERS_DATA_MC33771[i].name,
                     BCC_REGISTERS_DATA_MC33771[i].address,
                     regVal);
      } else {
        debug_printf("%d,%d,%s,0x%04X,ERROR_%d,Failed to read\r\n",
                     bcc_num, cid,
                     BCC_REGISTERS_DATA_MC33771[i].name,
                     BCC_REGISTERS_DATA_MC33771[i].address,
                     error);
      }
      delay(1); // Small delay between reads
    }
  } else {
    for (uint8_t i = 0; i < REG_CONF_CNT_MC33772; i++) {
      bcc_status_t error = bcc->read_register(cid, BCC_REGISTERS_DATA_MC33772[i].address, 1U, &regVal);

      if (error == BCC_STATUS_SUCCESS) {
        debug_printf("%d,%d,%s,0x%04X,0x%04X,Configuration register\r\n",
                     bcc_num, cid,
                     BCC_REGISTERS_DATA_MC33772[i].name,
                     BCC_REGISTERS_DATA_MC33772[i].address,
                     regVal);
      } else {
        debug_printf("%d,%d,%s,0x%04X,ERROR_%d,Failed to read\r\n",
                     bcc_num, cid,
                     BCC_REGISTERS_DATA_MC33772[i].name,
                     BCC_REGISTERS_DATA_MC33772[i].address,
                     error);
      }
      delay(1); // Small delay between reads
    }
  }
}

void dump_device_fuse_mirror(uint8_t bcc_num, bcc_cid_t cid, BatteryCellController *bcc, bcc_device_t device_type) {
  // MC33771C has fuses 0x00-0x17, MC33772C has 0x00-0x1F
  uint8_t max_fuse_addr = (device_type == BCC_DEVICE_MC33771) ? 0x17 : 0x1F;

  for (uint8_t addr = 0x00; addr <= max_fuse_addr; addr++) {
    uint16_t fuseVal;
    bcc_status_t error = bcc->read_fuse_mirror(cid, addr, &fuseVal);

    if (error == BCC_STATUS_SUCCESS) {
      debug_printf("%d,%d,FUSE_%02X,0x%02X,0x%04X,Fuse mirror data\r\n",
                   bcc_num, cid, addr, addr, fuseVal);
    } else {
      debug_printf("%d,%d,FUSE_%02X,0x%02X,ERROR_%d,Failed to read\r\n",
                   bcc_num, cid, addr, addr, error);
    }
    delay(1); // Small delay between reads
  }
}

void characterize_device(uint8_t bcc_num, bcc_cid_t cid, BatteryCellController *bcc, bcc_device_t device_type) {
  debug_printf("\n# Characterizing BCC%d Device %d (MC3377%s)\r\n",
               bcc_num, cid,
               (device_type == BCC_DEVICE_MC33771) ? "1" : "2");

  // Read GUID
  dump_device_guid(bcc_num, cid, bcc);

  // Read INIT register
  dump_device_init_register(bcc_num, cid, bcc);

  // Read all configuration registers
  dump_device_config_registers(bcc_num, cid, bcc, device_type);

  // Read all fuse mirror data
  dump_device_fuse_mirror(bcc_num, cid, bcc, device_type);
}

bool initialize_bcc0() {
  debug_println("\n=== Initializing BCC0 ===");

  // Setup device types (assuming MC33772C for 6-cell batteries)
  for (uint8_t i = 0; i < MAX_DEVICES; i++) {
    devices_0[i] = BCC_DEVICE_MC33772;
  }

  // Initialize SPI
  bcc0_tx_spi = new SPIClass(BCC0_TX_DATA, NC, BCC0_TX_SCK, NC);
  bcc0_rx_spi = new SPIClass(BCC0_RX_DATA, NC, BCC0_RX_SCK, BCC0_RX_CS);

  // Initialize TPL and BCC
  tpl0 = new TPLSPI(bcc0_tx_spi, bcc0_rx_spi, BCC0_TX_CS, configureDMA_HV_ECU);
  bcc0 = new BatteryCellController(tpl0, devices_0, MAX_DEVICES, CELL_COUNT,
                                   BCC0_ENABLE, BCC0_INTB, false);

  pinMode(BCC0_TX_CS, OUTPUT);
  digitalWrite(BCC0_TX_CS, HIGH);

  bcc_status_t error = bcc0->begin(nullptr);

  if (error == BCC_STATUS_SUCCESS) {
    debug_println("BCC0: Initialization successful");
    return true;
  } else {
    debug_printf("BCC0: Initialization failed with error %d\r\n", error);
    return false;
  }
}
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

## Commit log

2025-10-25 initial commit - working state for monitoring single bcc chain
2025-10-26 basic BMS implementation (single pack with charge control)
2025-11-04 Updated submodules and battery_char env
2025-11-12 Simple charger interface
2025-11-16 Implement libopeninv as an Arduino compatible library
2025-11-16 Update BMS + main to use Chademo implementation
2025-12-02 Add 0.2.0 hardware
    [HV ECU-B_Cu.gbr, HV ECU-B_Mask.gbr, HV ECU-B_Paste.gbr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]
2026-05-13 Wire up v1 hardware HAL and dedicated debug serial
    Switch the project onto the v0.2.0 board: route includes through
    hv-ecu-v1-pins.h, move debug output off SerialUSB/CDC onto USART1 via a
    small DebugSerial wrapper, and update platformio.ini to drop the CDC
    build flags and include ivt-s/can/ in the BRZ build.
2026-05-13 Use v1 pin map across app and add 10-LED SOC display mode
    Migrate main, BMS, battery_char, and CHAdeMO off SerialUSB onto
    DebugSerial. In main, configure the WAKEUP input and put the AC
    contactor pins into a safe-off default until the AC charging flow is
    implemented. Expand the status LED patterns to use all 10 LEDs on the
    v1 board and toggle the strip between BMS-state view and an SOC bar
    every 3 seconds once SOC is initialized.
2026-05-13 Add IVT-S error decoding and bring simple_charger onto v1
    Parse the MuxID/counter/status byte on every IVT-S frame so we can flag
    overcurrent, precision, measurement, and system errors plus detect
    counter gaps; track them as state on the shunt. Update simple_charger
    to the v1 pin map and DebugSerial, raise the measurement cadence under
    the MC33772 SYS_CFG2 COM_LOSS timeout, add JSON status emission, and
    wire in the IVT-S shunt for current/voltage telemetry during charging.
    [simple_charger.cpp]
2026-05-13 hardening/safety-critical: implement all S1-S12 items
    S1: Drive HV contactor pins safe (nSLEEP=LOW) at the very top of
    setup(), before serial or BCC init.
    S2: Add HVIL_DETECT_PIN INPUT_PULLUP in setup(); 3-read debounce in
    master_task_loop() triggers hv_disconnect + HV_Fault + BMS_Error.
    S3: Already done (CHAdeMO moved to hv_can in prior commit).
    S4: Add stack_voltage_bcc1_uv written by bcc1_monitor_task; fix all
    cell-count loops to use device_count * cell_count for both BCCs;
    fix packVoltage to sum both stacks; fix CELL_OFFSET to derive from
    bcc0 device_count * cell_count.
    S5: Funnel all contactor transitions through control_contactors();
    remove bare digitalWrite cal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
    [bms.cpp, main.cpp]
2026-05-13 hardening/io-and-logging: implement all L1-L10 items
    L1: duplicate DebugSerial definition was already removed in branch 1
    L2: remove #define Serial DebugSerial; replace all Serial. callsites with
    DebugSerial. across main.cpp, bms.cpp, battery_char.cpp, chademo.cpp,
    ivt_shunt.cpp, dma_config.cpp, simple_charger.cpp
    L3: add debug_serial_init() / debug_printf() / debug_println() wrappers
    with a FreeRTOS mutex (10ms timeout); replace all DebugSerial.printf/
    println callsites; call debug_serial_init() from setup() before tasks
    L4: gate HV CAN frame printing on hv_can_monitor_enabled — was
    unconditionally flooding USART1 at 500 kbps
    L5: remove dead m3_can_test_enabled/interva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
    [battery_char.cpp, bms.cpp, debug_serial.cpp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]
2026-05-13 infra/build-and-ci: implement all I1-I13 items
    - I1: Bump lib/bcc submodule pointer to 8c432e5 (committed separately)
    - I2: Pin all lib_deps to exact versions (remove ^ semver)
    - I3: Lift shared lib_deps (FreeRTOS, STM32_PWM, can_common) to [env]
    - I4: Add -Wall/-Wextra/-Werror=return-type/-Werror=format/-Wdouble-promotion,
    -fstack-usage, map file output to [env] build_flags
    - I5: Add .github/workflows/build.yml — builds hv-ecu + submodule drift check
    - I6: Add test/test_params/test_params.cpp — two unity smoke tests:
    default params safety bounds and IVT 0x521 current decode round-trip
    - I7: Deferred — web/ is simple-charger debug tooling, not firmware
    - I8: Delete src/hal/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
    [hv-ecu-v1-pins.h, main.cpp]
2026-05-13 Fix build warnings and errors surfaced by I4 warning flags
    - Add FW_VERSION_BUILD to gen_version.py output (was missing, caused error)
    - Remove unused last_debug variable in can_rx_task
    - Add #pragma GCC diagnostic to suppress -Wdouble-promotion for printf
    varargs promotion (inherent to printf calling convention on this target)
    - Add trailing newline to .gitignore
    [main.cpp]
2026-05-13 Move battery-char and simple-charger envs to platformio_override.ini
    These are local debug tools, not firmware. The override file is gitignored
    so it doesn't appear in CI or for other contributors.
2026-05-13 fix/bms-can: address all 14 review issues (bugs, correctness, minors)
    Bugs:
    - #1: tick100 init = 1 to prevent double 0x404 at boot
    - #2: add get_balance_mask() to BMS; rewrite send_0x402 to use it (eliminates voltage recomputation race and UINT32_MAX min_uv edge case)
    - #3: broadcast 0x7FFF for PackTemp in 0x356 — BCC NTC not yet wired
    - #4: remove dead precharge_state member and set_precharge_state() setter
    - #5: fix voltage overflow — 0x356 PackVoltage and 0x405 voltages now uint16 100 mV/LSB; 0x351 stays 10 mV/LSB with 655 V ceiling note
    Correctness:
    - #7: snapshot cell voltages once per task cycle; send_0x400_0x401/0x402/0x403 accept snapshot to eliminate redundant mutex grabs
    - #8: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
    [bms.cpp]
2026-05-13 feat: add 0x406 extended pack summary; keep 0x356 ecosystem-compatible
    0x356 reverted to int16 @ 10 mV/LSB (ecosystem standard for Victron/SMA/Fronius
    charger compatibility). Receivers that need high-voltage or high-resolution
    pack data should use 0x406 instead.
    0x406 — ExtPackSummary (new, 500 ms):
    - PackVoltage: uint32, 1 mV/LSB, little-endian — range 0–4294967 V
    - PackCurrent: int32, 1 mA/LSB, little-endian — positive = charging
    Also adds:
    - bms_can_protocol.dbc — DBC file covering all broadcast frames (0x351–0x406)
    - docs/bms_can_quickstart.md — integrator quickstart with hardware setup,
    frame summary, signal encodings, configuration parameter table, and
    UDS planned/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
2026-05-13 feat: bootloader + dual BCC chain init in FreeRTOS task context
    - Add bootloader with CRC-verified app jump and shared boot flags
    - Add gen_flash_image.py / upload_flash_image.py for combined flash images
    - Defer BCC begin() to FreeRTOS task context so INTB interrupts are live;
    pre-scheduler calls always timeout regardless of delay
    - BCC1 polls bcc0_initialized before init to avoid concurrent SPI/DMA contention
    - Merge 4 BMSCANBroadcaster tasks into 1 to reduce heap pressure
    - Add UDS server (bms_uds / bms_uds_tp) for live parameter updates
    - Fix duplicate DebugSerial definition in main.cpp
    - Exclude main_bms_can.cpp from hv-ecu build_src_filter
    - Default bcc0/bcc1DeviceCount params to 0 (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
    [bms.cpp, bms_uds.cpp]
2026-05-13 feat: dual BCC serial status, AN threshold config, fuse mirror dump
    - Add 1Hz serial status dump: cell voltages, stack, SOC, faults, IVT
    - Read AN voltages and fault registers from both BCC0 and BCC1
    - Disable all AN OT/UT fault thresholds post-init (default 1.16V OT
    trips on thermistor pins AN3/AN4 ~0.45V at room temp; thresholds
    to be restored once NTC B-value and pullup are characterised)
    - Add configure_an_thresholds() and an_voltage_to_temp_c() stub
    - Add bcc0/bcc1 temp fields (sentinel -1000.0f until NTC decoded)
    - Dump fuse mirror (0x00-0x12) after BCC0 init
    - Suppress noisy conversion error print; let measurement loop retry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
    [bms.cpp]
2026-06-05 feat: BMS_M3_CAN feature flag, aux contactor config, CP pilot current cap, UDS param refactor
    - Gate Tesla M3 PCS/CAN code behind BMS_M3_CAN preprocessor flag; non-M3 path
    uses set_hv_can() and skips m3_can/m3_mgr entirely
    - Add M3CANManager::process_can_frame() to receive 0x21D CP pilot current
    (8-bit, 0.5A/LSB); BMS charging tick caps 0x2B2 power request accordingly
    - Replace auxContactorMode/auxPin0Role/auxPin1Role/nacsPin/nacsDcLevel params
    for kRole0-kRole3 placeholders; hv_connect() branches on mode to close both
    contactors immediately (AC) vs. running precharge sequence
    - Split holdDuty into per-pin holdDuty0/holdDuty1; read live from params in
    control_contactors() alongside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
    [bms.cpp, clock_config.cpp]
2026-06-05 feat: add pcsEnabled as runtime UDS param (DID 0xD302)
    PCS_ENABLED is a persisted param rather than a compile-time flag — BMS_M3_CAN
    gates the M3 CAN hardware/code, and pcsEnabled controls at runtime whether the
    BMS sends Tesla PCS messages (0x20A/0x22A/0x212/0x3B2/0x2B2). Default 0 so PCS
    is opt-in after flashing. Also fixes hv_can_task_loop/wrapper guards — the
    generic HV status broadcast (0x400) doesn't require BMS_M3_CAN.
    [bms.cpp, bms_uds.cpp]
2026-06-06 revert: remove pcsEnabled param and DID 0xD302
    PCS state is implicit in HVP_pcsControl (0x22A) driven by the HV state machine —
    no separate enable flag needed. BMS_M3_CAN remains the compile-time gate for
    having M3 CAN hardware.
    [bms.cpp, bms_uds.cpp]
2026-06-06 feat: UDS DID audit — replace k_role, add missing DIDs, fix persistence
    - Remove stale 0xD007/0xD008 (temp min/max) and 0xD00C (temps all) — returned
    hardcoded 0x7FFF with no BCC wiring; will re-add when AN3/AN4 are connected
    - Replace k_role[0-3] at 0xD200-0xD203 with named aux contactor params:
    auxContactorMode/auxPin0Role/auxPin1Role/nacsPin; add nacsDcLevel at 0xD207
    - Add 0xD302/0xD303: bcc0/bcc1DeviceType (MC33771 vs MC33772)
    - Add 0xD400-0xD405: canNodeId, pwmFrequency, engageDuty, holdDuty0/1, engageTime
    - Add 0xD500-0xD50A: batteryCapacity, min/max/initSoc, balanceTimer,
    measureInterval, balanceHvOffMin, ivtConfigured, prechargeCheckInt,
    commTimeout, faultCheckInt
    - Fix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
    [bms_uds.cpp]
